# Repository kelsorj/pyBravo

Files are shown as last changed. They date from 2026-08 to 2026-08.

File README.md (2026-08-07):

## In memory of Ben Shamah

This project exists because of Ben Shamah (1973–2018).

Ben studied mechanical engineering at UC San Diego and robotics at Carnegie
Mellon, where he worked on NASA-funded robots built to explore other planets.
He brought that work back down to the bench, joining Velocity11 to build
machines that would speed up medical research — and it was there, with
colleagues including Brad Nelson, Dave Assmusen, and Chris Shaw, that the Bravo
was born. He later co-founded BioNex Solutions and led its technical side.
People who worked with him describe someone quiet and generous, who liked
puzzling out hard engineering problems and liked helping other people solve
theirs even more. He died of cancer in 2018, at 45.

The Bravo is a genuinely good machine, and a lot of them are still running. The 
goal here is to let the hardware Ben helped design join the open source 
community.

---

# pyBravo

An open-source Python driver and web control system for Bravo liquid handling
robots. It connects to the instrument over Ethernet or serial, exposes every
motion and liquid-handling operation through a REST API and a browser UI, and
runs complete pipetting workflows. It has a full simulation mode so you can
build and test protocols without touching hardware.

```bash
git clone https://github.com/kelsorj/pyBravo.git
cd pyBravo
./scripts/start_pybravo.sh      # Windows: scripts\start_pybravo.bat
```

Then open <http://localhost:8000>. Out of the box the server runs against a
simulated robot, so this works on any machine.

> [!WARNING]
> This software drives a physical robot with enough force to break labware,
> crush a pipette head, or injure a hand. Read
> [docs/safety.md](docs/safety.md) before you connect to real hardware, and
> dry-run every new protocol in simulation first.

https://github.com/user-attachments/assets/48de0bf6-f5a1-409d-ab84-00fcac42d9b6

---

## What it does

- **Direct hardware control** — connect, initialize, home, move, and jog every
  axis, with live position and state streaming over WebSocket.
- **Liquid handling** — aspirate, dispense, and mix, with configurable liquid
  classes and pipette techniques.
- **Tips and labware** — tip pickup and ejection, an editable labware catalog,
  gripper pick-and-place, and lid handling.
- **Visual workflow designer** — build protocols as a node graph in the
  browser, simulate them, then run them on the instrument.
- **Deck management** — a 3×3 deck model with per-location teachpoints, and
  obstacle-aware Z clearance when the gripper carries plates between locations.
- **3D digital twin** — watch a URDF model of the robot mirror the real
  machine's position in real time.
- **Simulation mode** — the full motion, liquid-handling, and workflow stack
  runs with no hardware attached. The optional accessories below are the
  exception: they talk to real serial ports.
- **Optional extras** — camera-based deck verification, barcode reading,
  orbital shaker control, and an LLM-assisted protocol drafter.

## Supported hardware

| Instrument generation | `controller_type` | Connection |
|---|---|---|
| Darwin-generation Bravo | `darwin_native` | TCP, port 7613 |
| Agile 7612 Bravo | `agile_7612` | TCP, port 7612 |
| Bravo SRT | `agile_srt` | TCP, port 7612 |
| Legacy Agile Bravo | `agile` | Serial, or TCP port 10000 |
| No hardware | `simulation` | — |

Details and wiring notes are in [docs/hardware-setup.md](docs/hardware-setup.md).

## Documentation

Start with the [documentation index](docs/README.md). The most-used pages:

| Page | What it covers |
|---|---|
| [Installation](docs/installation.md) | Requirements and install paths for macOS, Linux, and Windows |
| [Quickstart](docs/quickstart.md) | First run in simulation, then your first real move |
| [Hardware setup](docs/hardware-setup.md) | Networking, finding your robot, profiles, teachpoints |
| [Safety](docs/safety.md) | What can go wrong and how to avoid it |
| [User guide](docs/user-guide.md) | The web UI, end to end |
| [Workflows](docs/workflows.md) | Building and running protocols in the designer |
| [Configuration](docs/configuration.md) | Profiles, environment variables, config files |
| [API reference](docs/api-reference.md) | Every HTTP and WebSocket endpoint |
| [Architecture](docs/architecture.md) | How the codebase fits together |
| [Protocol specification](docs/protocol-spec.md) | The instrument wire protocols |
| [Troubleshooting](docs/troubleshooting.md) | Symptoms, causes, fixes |
| [FAQ](docs/faq.md) | Common questions |

## Requirements

Python 3.11 or newer. The launcher scripts use [uv](https://docs.astral.sh/uv/)
when it is available, which installs a suitable Python and all dependencies
automatically; see [Installation](docs/installation.md) for the alternatives.

## Contributing

Contributions are welcome — see [CONTRIBUTING.md](CONTRIBUTING.md) for how to
set up a development environment, run the tests, and submit a change. Please
also read the [Code of Conduct](CODE_OF_CONDUCT.md). To report a security
issue, follow [SECURITY.md](SECURITY.md).

## License

pyBravo is an independent project. It is not affiliated with, endorsed by, or
supported by Agilent Technologies, Inc. Product names are trademarks of their
respective owners and are used only to identify the hardware this software
runs. See [NOTICE](NOTICE) for the full trademark statement.

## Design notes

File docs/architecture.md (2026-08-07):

# Architecture

How pyBravo is put together, for people who intend to change it. If you only
want to run the software, start with the [Quickstart](quickstart.md) instead.

## The shape of the system

pyBravo is a layered stack. Each layer talks only to the one below it, which
is what makes it possible to support four instrument generations plus a
simulator behind one API.

```
Browser UI  (frontend/)
     │  HTTP + WebSocket
     ▼
Web layer  (pybravo/web/server.py)
     │  method calls
     ▼
Bravo facade  (pybravo/bravo.py)
     │
     ├──▶ State machine  (pybravo/state_machine/)   high-level operations as abortable tasks
     ├──▶ Deck / labware  (pybravo/deck/)           what is on the deck, and where
     ├──▶ Motion          (pybravo/motion/)         kinematics, speed profiles, path planning
     └──▶ Controller      (pybravo/controllers/, pybravo/darwin/)
                │  one class per instrument generation
                ▼
          Protocol codecs  (pybravo/protocol/)      framing, packets, CRC
                │
                ▼
          Transport        (pybravo/transport/)     TCP or serial bytes
```

The important boundary is `pybravo/controllers/base.py`. It defines the
abstract interface every backend implements — connection, motion, homing, motor
enable, device state, gripper, head detection. Everything above that line is
hardware-independent. Adding support for a new instrument means writing a new
class that satisfies that interface, and nothing above it needs to change.

## Layer by layer

### Web layer — `pybravo/web/`

`server.py` is a single large FastAPI application holding roughly 129 HTTP
routes plus one WebSocket. Routes are declared with a `_route_meta(tag, summary,
description)` helper that feeds FastAPI's OpenAPI schema, so the live
interactive docs at `/docs` stay in sync with the code. `middleware.py` logs
requests.

The single WebSocket, `/ws/state`, pushes the same payload as `GET /api/state`
on a loop. It polls at roughly 30 Hz against the simulator, and throttles to
5 Hz for real hardware so that state polling does not saturate the wire
protocol.

The web layer holds one global `Bravo` instance. It does not talk to hardware
directly.

### Facade — `pybravo/bravo.py`

The `Bravo` class is the API that applications use. It owns the profile, picks
and constructs the right controller from `profile.connection.controller_type`,
and wires together deck state, head configuration, and the state machine. If
you are writing a Python script against this project rather than using the web
UI, this is your entry point.

### State machine — `pybravo/state_machine/`

Every high-level operation — initialize, home, move to location, pick and place,
delid, aspirate, dispense, mix, tips on, tips off, scan stack height — is a
task object in `tasks.py`. `engine.py` runs them with support for abort, retry,
and ignore, which is what lets the UI recover from a recoverable error instead
of dying.

`tasks.py` is large. It is the single place where "what the operator asked for"
becomes "the ordered sequence of axis moves that accomplishes it," so it
concentrates a lot of the domain knowledge about doing things safely.

### Deck and motion — `pybravo/deck/`, `pybravo/motion/`

`deck/` models a 3×3 deck: which labware sits at each location, teachpoints for
each location, and stack tracking. `motion/` converts engineering units to
encoder ticks, applies per-axis speed profiles, and plans paths that keep the
head above obstacles.

These are pure software models. Nothing here senses the physical world, which
is why a mismatch between the model and reality causes crashes — see
[Safety](safety.md).

### Controllers — `pybravo/controllers/`, `pybravo/darwin/`

| Backend | Class | Notes |
|---|---|---|
| `simulation` | `SimulationController` | Tracks position in software; no I/O |
| `agile` | `AgileController` | Legacy instruments; serial or TCP 10000 |
| `agile_7612` | `Agile7612Controller` | Subclasses `AgileController`; TCP 7612 |
| `agile_srt` | `AgileSrtController` | Subclasses `Agile7612Controller`; four axes, no gripper |
| `darwin_native` | `DarwinController` | Separate stack under `pybravo/darwin/`; TCP 7613 |

The Agile family forms an inheritance chain, because each generation is a
variation on the one before. Darwin-generation hardware speaks a different
protocol entirely and gets its own package, with per-axis state machines for
commutation, homing, and initialization in `darwin/axis.py`.

### Protocol and transport — `pybravo/protocol/`, `pybravo/transport/`

`protocol/` holds the codecs: frame headers, packet structures, CRC, and
command encoding. The `gemini/` subpackage implements the protocol used by
Darwin-generation firmware; the `agile_7612_*` modules implement the other
family. See [Protocol specification](protocol-spec.md) for the wire formats.

`transport/` is deliberately thin — it moves bytes over TCP or a serial port
and knows nothing about their meaning. This split is what makes the protocol
layer testable with a mock transport and no hardware.

## Supporting subsystems

- **`pybravo/profile/`** — YAML-based per-machine configuration, replacing the
  Windows registry configuration older systems used. `reg_import.py` reads
  registry profile exports and legacy `.dat` directory trees so an existing
  instrument's configuration can be migrated.
- **`pybravo/workflow/`** — the node-graph protocol system: `models.py` for the
  data model, `storage.py` for JSON persistence, and `executor.py`, which walks
  the graph and dispatches state-machine tasks. The `drafter/` subpackage is the
  optional LLM assist.
- **`pybravo/vision/`** and **`pybravo/vision_service.py`** — optional
  camera-based deck verification. The camera runs in a *separate* process
  (default port 8101) because the SDK is a heavy, optional dependency; the main
  server talks to it over HTTP via `vision_client.py`, and works fine when it is
  absent.
- **`pybravo/accessories/`** — barcode reader and orbital shaker drivers, with a
  manager handling their lifecycle.
- **`pybravo/model/`** — the URDF robot model and meshes that the browser renders
  as a live digital twin.

## How a request becomes motion

Tracing `POST /api/move` end to end:

1. FastAPI parses the request and calls the handler in `server.py`.
2. The handler calls the corresponding method on the global `Bravo` instance.
3. `Bravo` creates the appropriate task and hands it to the state machine
   engine, which can abort or retry it.
4. The task consults motion and deck state to turn the requested engineering
   units into a safe target in encoder ticks.
5. The task calls the controller's `move` method — the first hardware-specific
   step.
6. The controller encodes the command through the protocol codec.
7. The transport writes bytes to the socket or serial port.
8. Position updates flow back up and are broadcast to every browser over
   `/ws/state`.

## Testing strategy

The transport boundary is what makes this testable. Most protocol and
controller tests substitute a mock transport that replies with well-formed
frames, so the full encode/decode path runs with no instrument attached.

- `tests/protocol/gemini/` — codec-level tests for framing, packets, instructions
- `tests/darwin/` — axis state machines, homing, safety limits, motion, topology
- `tests/test_agile_srt_homing.py` — a golden-file test pinning the SRT homing
  frame sequence, because homing is the operation most likely to damage hardware
  and cannot be exercised in CI
- `tests/test_web_server.py` — API endpoint behavior
- `tests/test_bravo_init.py` — the facade's behavior, the largest suite

Run everything with `uv run --extra dev python -m pytest`.

## Extending it

**A new instrument generation:** subclass `BravoController` (or the closest
existing Agile class), implement the interface, add your `controller_type` to
the selection logic in `pybravo/bravo.py`, and add a profile. If the wire format
differs, add a codec under `pybravo/protocol/` rather than putting encoding
logic in the controller.

**A new high-level operation:** add a task in `pybravo/state_machine/tasks.py`,
expose it on `Bravo`, then add a route. Keeping the logic in the task means it
works from the API, from the workflow executor, and from a Python script.

**A new workflow node:** add the node type to the designer, then map it to a
task in `NODE_TYPE_MAP` in `pybravo/workflow/executor.py`.

**A new accessory:** add a driver under `pybravo/accessories/` and register it
with the manager.

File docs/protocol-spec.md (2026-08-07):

# Protocol specification

The wire protocols pyBravo speaks to Bravo instruments. This page is for
people maintaining the driver or adding support for another instrument
generation; you do not need it to operate the software.

Two protocol families are implemented. Which one applies depends on your
instrument's controller generation.

| Family | Instruments | `controller_type` | Port |
|---|---|---|---|
| Gemini | Darwin-generation | `darwin_native` | TCP 7613 |
| V11 / Agile | Agile, Agile 7612, SRT | `agile`, `agile_7612`, `agile_srt` | TCP 7612, TCP 10000, or serial |

Neither protocol has authentication or encryption. Anyone with network access to
the instrument can command it — see [SECURITY.md](../SECURITY.md).

## Gemini protocol (Darwin-generation)

Implemented in `pybravo/protocol/gemini/`.

### Outer TCP frame

Every message is an 8-byte header followed by a payload:

| Offset | Size | Field | Value |
|---|---|---|---|
| 0–1 | 2 | `msg_sync` | `0xAAAA`, little-endian |
| 2–3 | 2 | `protocol_version` | `0x0001`, little-endian |
| 4–5 | 2 | `payload_type` | little-endian uint16 |
| 6–7 | 2 | `payload_size` | little-endian uint16, bytes following |
| 8… | n | `payload` | interpreted per `payload_type` |

### Payload types

| Value | Name | Payload |
|---|---|---|
| 1 | `PACKET` | Exactly 8 bytes — one packet |
| 4 | `MULTIPACKET` | Up to 512 bytes. Outgoing: N concatenated 8-byte packets. Incoming: an 8-byte response |
| 5 | `SERIAL_DATA` | Exactly 9 bytes — a serial-peripheral payload |

Packet encoding, instruction encoding, and the enum tables live in
`packet.py`, `instruction.py`, and `enums.py`. An instruction is the 4-word
encoding used for motion, delay, and tip operations.

### Axis control

Darwin-generation axes are not initialized through a single firmware call.
Commutation, homing, and initialization are each driven step by step through
`SUBCMD_MOTOR_STATE` writes and polled state reads, implemented as per-axis
state machines in `pybravo/darwin/axis.py`. Driving them explicitly is what
makes retry-on-regression and the timing-sensitive behavior possible.

## V11 / Agile protocol

Implemented in `pybravo/protocol/agile_packet.py`,
`agile_7612_packet.py`, `agile_7612_commands.py`, `agile_7612_crc.py`,
`v11_comm.py`, and `v11_agile_7612_comm.py`.

### Frame order differs by generation

This is the single most important difference, and getting it backwards produces
frames the instrument silently ignores:

- **Legacy Agile:** `[length][cmd][data]`
- **Agile 7612 and SRT:** `[cmd][length_u16_LE][data]`

### Checksum

Agile 7612 and SRT use **CRC-8/MAXIM** (Dallas 1-Wire): polynomial `0x8C`, the
reflected representation of x⁸+x⁵+x⁴+1, with `init=0x00`. This is *not*
CRC-8/SMBUS (`0x07`), and the two agree often enough on short inputs to make a
mistake here hard to spot.

### Agile packets

Command `0xA1` frames carry a 10-byte Agile packet followed by a one-byte axis
index. Byte semantics that matter:

- **Byte[1]** is the axis bitmask for status and trigger commands.
- **Byte[7]** carries the register or operation selector. Notably, the status
  register `0x90` goes in **byte[7]**, not byte[1] — a common error.

Selected byte[7] values:

| Value | Meaning |
|---|---|
| `0x10` | Servo register write |
| `0x31` | Fault reset |
| `0x38` | Move trigger |
| `0x52` | Homing-complete marker |
| `0x90` | Status read |

### Motion commands

| Command | Purpose |
|---|---|
| `0xA2` | `PREPARE_MOVE` — 17-byte struct on Agile 7612 and SRT |
| `0xAA` | `PREPARE_JOG` — force-controlled moves only |
| `0xA7` | Position read |

`PREPARE_JOG` (`0xAA`) is used **only** for force-controlled tip pickup.
Ordinary jogs from the UI use `PREPARE_MOVE` (`0xA2`) followed by a trigger
(byte[7] = `0x38`). Using `0xAA` for a normal jog applies force where none is
wanted.

### Header selection

Servo register writes use a header of `local_axis * 0x10`. Two operations do
not follow that rule:

- **Home-complete register writes** use header `0x01`.
- **The homing-complete marker** (byte[7] = `0x52`) uses header `0x00`.

### Homing

Homing is host-driven and stateful. The ordering constraints are real
requirements, not conventions:

1. Register `0x4A` must be **read** before homing begins.
2. After servo configuration, register `0x10` must be **read** via header
   `0x09`. Without both reads the firmware never enters homing mode, and the
   failure is silent.
3. The phase pattern is chosen at runtime from the home-sensor state in register
   `0x10`: on-sensor gives a 2-phase home (depart, then slow approach back);
   off-sensor gives a 3-phase home (approach, depart overshoot, slow approach).
4. A homing-complete marker (byte[7] = `0x52`) is sent per axis, with an empty
   data field. The X and Y markers can carry situational data bytes; those must
   not be replayed from one homing scenario into another.

`tests/test_agile_srt_homing.py` pins the complete SRT homing frame sequence,
because homing is the operation most likely to damage hardware and cannot be
exercised in CI.

### Generation-specific notes

**Agile 7612.** Two servo controllers, indexed 0 and 4. Controller 2 requires a
fault reset (mask `0x01`, axis index 4, byte[7] = `0x31`) after **every** move,
not only during G-axis homing. The firmware supports neither ADC head read
(`0xB3`, which causes audible clicking) nor smart head detect (`0xB5`), so head
type must be configured manually.

**SRT.** Four axes — X, Y, Z, W — with no gripper, and four servo controllers
indexed 0–3, so homing servo headers are `0x00`, `0x10`, `0x20`, `0x30`. Homing
order is Z, W, X, Y. The home-complete register field in `PREPARE_MOVE` is
encoded `0x01nn`. The W (pipettor) axis needs a pump-parameter pre-config block
written before its homing servo configuration, and a distinct register-`0xA0`
value.

## Units and scaling

Positions cross the wire as encoder ticks. Conversion to engineering units uses
each axis's `ticks_per_eng_unit` from the profile.

The W axis is the trap: its `ticks_per_unit` must come from the profile
(448.0), not the inherited default (48.0). A wrong value here means every
volume is wrong by roughly a factor of nine.

## Known measurement limitations

- The W position register is unstable, with a spread of roughly 5–10 µL between
  consecutive reads. Static readings are directionally correct but noisy.
- Controller 2 position reads (G and Zg) are unreliable while motion is active.
  At-rest values are correct.

## Adding a new generation

Add a codec under `pybravo/protocol/` and a controller under
`pybravo/controllers/` implementing the interface in `base.py`. Keep encoding in
the codec, not the controller. The transport layer is deliberately thin, so a
mock transport lets you test the full encode/decode path with no instrument —
see [Architecture](architecture.md).

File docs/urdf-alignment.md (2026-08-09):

# URDF head alignment (3D view only)

> **Status: all three axes are fixed.**
>
> - **Z — done.** The head was drawn one teach-tip too low. Corrected via the
>   live `head.teach_tip_length_mm`; see "The Z axis" below.
> - **X and Y — done.** Fixed as measured gantry datums in `JOINT_AXIS_MAP`
>   (`xaxis: 182.64`, `yaxis: 2.3`), not by moving the drawn tips; see "The X/Y
>   datum" below. Two earlier attempts moved the tips instead of the gantry and
>   were reverted — "Two alignments, not one" below explains why that can never
>   work, and remains the most useful thing on this page.
>
> All of this is cosmetic. Real motion is unaffected.
>
> **Confirmation recording:**
> [docs/media/tips-on-off-simulation.mov](media/tips-on-off-simulation.mov) — a
> simulate run captured after the fixes: the head descends aligned with the
> box, the tips leave the box and attach at the bottom of the press, ride up
> with the head, and are released into the destination box at the eject.
> (GitHub plays committed videos from the file's blob page; open the link.)

> **Scope: the 3D view, and nothing else.**
>
> Real motion is correct. Tips on and tips off work on hardware in full, row,
> column and partial modes, on both 96 and 384 heads. The commanded positions,
> the teachpoints, and the geometry in `pybravo/deck/geometry.py` and
> `pybravo/head_mode.py` are therefore **authoritative and out of scope**.
> Nothing described here may change a commanded position, and no change made
> for the reasons in this document belongs anywhere except
> `frontend/src/robot-scene.js`.
>
> If a proposed change to the 3D view would require editing anything under
> `pybravo/`, the proposal is wrong.

## The problem this existed to solve

In the 3D view the head's barrels were drawn a couple of columns away from the
wells they were actually over — worst at the edge of an empty tip box, where
the tips visibly hung off the end.

## The X/Y datum — diagnosed and fixed

The error was in the gantry's visual datum, not in where the tips sit on the
head. Measured with the head-tip array (placed from the head mesh) against the
rendered wells, at four commanded poses spanning 99 mm of X travel and both
deck rows:

| | error, every pose |
|---|---|
| X | **−10.40 mm** (≈2.3 columns), constant |
| row (robot Y) | **+2.40 / +2.19 mm** per location (mean ≈ half a pitch) |

Constant across the whole span in both axes — a datum error, not scale. Both
derivatives measured exactly 1 mm world per commanded mm, so the correction is
a pure `homeOffset` shift in `JOINT_AXIS_MAP` (`frontend/src/robot-scene.js`):
`xaxis` 193.04 → **182.64**, `yaxis` 0 → **2.3**. After the change the residual
is 0.00 mm in X and ±0.11 mm in row at all four poses — the ±0.11 is the two
locations' real taught difference, which a flat model deck cannot represent.

Why this works where the two reverted attempts could not: `homeOffset` moves
the **whole gantry chain** — head mesh, attached tips, and gripper together, as
on the real machine (they share one carriage; confirmed against the URDF joint
tree, where both hang under `ygantry` ← `xgantry`). The tips↔mesh relationship
is preserved by construction (barrel-to-tip gap 17.9 mm before and after), and
deck pads and labware are static children of the base and do not move. The
earlier attempts moved only the drawn tips, which can satisfy tips↔labware or
tips↔mesh but never both.

The remaining per-location ±0.1 mm class of residual would only be removable by
modelling the deck's taught Z/XY variation, which is not worth it for a
visualization.

This document is the definition the renderer should use instead.

## The invariant

> When the robot is commanded to a position, the **rendered** head's A1 barrel
> must appear at the deck position that command implies — for every head type,
> every labware format, and every head mode.

Equivalently, and more usefully as a test: when a tip operation is commanded
against the A1 anchor of a piece of labware, the rendered A1 barrel sits on the
rendered A1 well.

## Two alignments, not one

This is the trap that has already cost a round of work. There are two
relationships, and a change to the drawn tip positions trades one against the
other:

| | what it means | how it is currently satisfied |
|---|---|---|
| tips ↔ head mesh | the drawn tips sit under the head's visible barrels | correct today, because the tips are placed from the mesh bounding box |
| tips ↔ labware | the drawn tips sit over the wells they are commanded to | wrong today, by the constant above |

Moving the drawn tips can only ever satisfy one of these. Fixing this properly
means establishing where A1 is **in the model**, so both hold at once.

**Any verification must check both.** A measurement that only checks tips against
labware will report success while the tips float away from the head.

## What the backend already fixes for us

Read-only facts, established from the code. These are inputs to the render, not
things to change.

**Barrel grids** — `head_geometry_for_type`, `pybravo/head_mode.py`:

| head type | grid (rows × cols) | pitch |
|---|---|---|
| `HT_384_D_70`, `_S2`, `HT_384_F_50`, `HT_384_PINTOOL` | 16 × 24 | 4.5 mm |
| 96-format (the fallback) | 8 × 12 | 9.0 mm |
| `HT_1536_PINTOOL` | 32 × 48 | 2.25 mm |
| `HT_16_D_ST` | 16 × 1 | 4.5 mm |
| `HT_8_D_LT` | 8 × 1 | 9.0 mm |

**Corner and axis conventions** — pinned by the Head Mode picker, which draws
BACK as −Y, LEFT as −X, and marks the anchor corner at back-left:

- A1 is the **back-left** barrel: minimum X, minimum Y.
- Column index increases toward **+X** (right).
- Row index increases toward **+Y** (front).

**Head A1 offsets between formats** — from the hardware, not from code: the
384 head's A1 barrel sits **2.25 mm left and 2.25 mm back** of the 96 head's A1
barrel. The two grids are concentric at different pitches, so their A1 corners
do not coincide.

## How this was defined in the end

The original plan on this page was a per-head-link constant (`A1_OFFSET`,
placing the barrel array within the head link). The fix that actually shipped
is simpler and sits one level up: the error was the same for the whole gantry,
so it lives in the per-joint `homeOffset` datums in `JOINT_AXIS_MAP`, and the
tips stay placed from the head mesh exactly as before. A per-head constant
would only become necessary if a head's *mesh* were misplaced within its own
link — no evidence of that once the gantry datum was corrected.

If a future head model does need a per-link constant, the measurement
procedure is unchanged: command the A1 anchor over a known box, read where the
mesh's barrels render versus the wells, at two distant locations (the value
must be constant), and for the 96/384 pair check their difference comes out at
(2.25, 2.25) — the two grids are concentric at different pitches.

## Verification

A fix is only complete when all of these hold:

1. **tips ↔ labware**: the rendered A1 barrel sits on the rendered A1 well when
   commanded to the A1 anchor, for both head formats.
2. **tips ↔ head mesh**: the rendered tips sit under the head mesh's own
   barrels — checked visually and by comparing tip positions against mesh
   barrel positions.
3. **Pose independence**: both hold at several positions across the deck, not
   just the one used to derive the constant.
4. **Mode independence**: both hold for full, row, column and partial modes.
5. **`git diff --name-only -- pybravo/` is empty.** No Python changed, so no
   commanded position can have changed.

## The Z axis — diagnosed and fixed

The head rendered one **teach tip** too low, at every Z.

Robot Z is referenced to the tip of the teach tip, not to the barrel face: the
backend computes `deck_surface_z = teach_z + teach_tip_length`. The renderer
placed the head as though Z meant the barrel, so it sat low by exactly that
length.

Measured against the deck surface, head mesh only, with the synthetic tips
excluded — they are children of the head link and contaminate the measurement
if included, which is how an earlier pass produced a spurious 44.1 mm:

| | before | after |
|---|---|---|
| loc 1 (50 mm box), Z = 0, 50, 100, 115.1, 140, 165.1 | −26.14 mm at every Z | **−0.04 mm** |
| loc 4 (25 mm box), Z = 0, 50, 100, 115.1, 140, 164.9 | −25.94 mm at every Z | **+0.16 mm** |

Constant across Z, independent of labware height, and −26.04 mm on average
against a nominal `teach_tip_length_mm` of 26.1. The residual ±0.1 mm is the
0.20 mm difference between the two locations' taught Z, which a flat model deck
cannot represent — it is real machine variation, not modelling error.

The fix uses the `homeOffset` mechanism already present in `JOINT_AXIS_MAP`,
which at the time was calibrated for X (193.04 — since re-measured to 182.64,
see "The X/Y datum" above) and Zg (−20) but left at 0 for Z. The value
is taken live from `head.teach_tip_length_mm` on `/api/profile` rather than
hardcoded, so a different head or teach tip follows automatically, with the
common 26.1 seeded as a fallback.

Two things were checked because they could have been broken silently:

- **Tips still sit on the head.** The gap between the barrels and the tips'
  bottoms is 17.9 mm before and after. The whole head link moves, so this
  relationship is preserved by construction — unlike the X/Y attempts, which
  moved only the drawn tips.
- **The gripper did not move.** `zaxis-gripper` is coupled to Z, so it could
  have been dragged along; measured at 87.8 mm before and after, unchanged.

### `tip_offsets.yaml` was never the problem

Worth stating plainly, because it is the intuitive place to look. The backend
already resolves `config/tip_offsets.yaml` and folds the result into the
commanded Z: `deck_surface_z - labware_height`, then the eject offset. Moving
between the Tips On and Tips Off poses raised the head by exactly 14.2 mm in the
view, which is `tips_off_z_offset: 14.0` arriving intact.

**Those offsets are therefore already in the Z the renderer receives, and must
not be applied again there — that would double-count them.** What the view was
missing was the datum, not the offsets.

### A more durable version of this fix

The backend computes `deck_surface_z` in the tips motion path (`executor.py`)
but does not send it to the frontend. Sending it would let the renderer derive
the Z datum from the deck directly, rather than reconstructing it from the teach
tip length. Worth doing if this ever drifts again.

## Open questions

- The X/Y/Z datums were measured with the 384 head model. If a 96-head mesh is
  ever added to the URDF, re-run the four-pose sweep with it — the gantry
  datums should hold (they are properties of the gantry, not the head), and any
  residual would indicate the new head mesh is misplaced within its link.
- The datums are tied to this revision of the URDF. If the URDF is re-exported,
  re-measure — the sweep takes minutes and the procedure is above.

## Notes for whoever picks this up

The renderer currently falls back to `_getHeadTipMountFrame` whenever it lacks
better information, which is the right shape — keep a fallback so the tips are
always drawn somewhere sane, and prefer the defined constant when available.

Be aware that the designer pauses the `/ws/state` socket while a simulation runs
(`setSimulationMode`), so anything the renderer needs from server state must not
depend on that socket being live. A previous attempt at this fix was correct but
never executed for exactly that reason.

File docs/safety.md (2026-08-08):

# Safety

pyBravo drives a physical robot with motors strong enough to break labware,
destroy a pipette head, and injure a hand. This page is the one document you
should read before connecting to real hardware.

> [!WARNING]
> This software is provided under the GNU General Public License v3.0 or later,
> **without warranty of any kind and without any fitness-for-purpose
> guarantee**. It is not a
> validated instrument control system, it is not certified for clinical,
> diagnostic, or GxP use, and it has not been safety-certified by any body. You
> are responsible for the safe operation of your instrument.

## The short version

1. Simulate first. Every new or edited protocol runs in `simulation` before it
   runs on metal.
2. Keep a hand near the emergency stop the first time any new motion executes.
3. Verify teachpoints after any mechanical change, head swap, or deck change.
4. Never run a workflow you have not read, including one generated for you.
5. Watch the first full run of any protocol end to end. Do not walk away.

## What can actually go wrong

**Head-into-deck crash.** The Z and W axes carry the pipette head down toward
the deck. A wrong teachpoint, a wrong `ticks_per_eng_unit`, a labware
definition with the wrong height, or a plate that is present when the software
thinks the location is empty will drive the head into a hard surface. This is
the most common way to cause expensive damage, and it happens fast enough that
you cannot react in time. It is prevented by correct configuration, not by
reflexes.

**Crash during homing.** Homing moves axes toward their limits, sometimes at
speed, and it runs before the software knows where anything is. If the deck is
not clear, homing is when you find out. Clear the deck before homing.

The order matters and is enforced in code (`SAFE_HOME_ORDER` in
`pybravo/types.py`): **Z, then Zg, then G, then X and Y, then W.** The head and
gripper must lift before the gantry moves laterally, or an unhomed head sitting
low is dragged sideways through whatever is on the deck. `HomeTask` also tries
to retract Z and dock the gripper first, but both of those steps are skipped
when the axes are not yet homed — which is exactly the cold-start case — so the
ordering is the real guarantee. Do not reorder it without understanding what is
physically above the deck at each step.

Sequence axes on the server, never in a client. `POST /api/home_axis` accepts
`{"axes": ["X", "Y", "Z"]}` and orders the group; issuing one request per axis
bypasses the invariant entirely, because a single-axis request has no order to
correct.

**Gripper and pick-and-place collisions.** Moving labware between locations
assumes the destination is empty and the path is clear. If the deck state in
software disagrees with the deck in front of you, the robot will move as though
its model is correct.

**Tip pickup force.** Tip pickup presses the head down onto a tip box with
deliberate force. A misaligned tip box, the wrong tip definition, or a wrong
head mode turns that force into damage.

**Pinch and crush points.** The moving head and gripper have no light curtain
in most configurations. Do not reach into the work envelope while the
instrument is powered and enabled, even when it appears idle — a queued command
or a network message can start motion with no warning.

**Liquid hazards.** The software does not know what is in your plates. Aspirate
and dispense operations with the wrong volumes or the wrong liquid class can
spray, aerosolize, or cross-contaminate. Apply your own lab's handling rules for
whatever is on the deck.

## Before you connect to hardware

- Read [Hardware setup](hardware-setup.md) and build a profile for your
  specific instrument. Do not reuse another lab's profile: teachpoints, axis
  ranges, and calibration are machine-specific.
- Confirm `controller_type` matches your instrument generation. Speaking the
  wrong protocol to a robot produces undefined behavior.
- Confirm axis ranges and `ticks_per_eng_unit` are right. If ticks-per-unit is
  wrong, a commanded 10 mm move can travel 100 mm.
- Know where the emergency stop is, and confirm it works, before the first move.
- Clear the deck.

## Before each run

- Confirm the deck in software matches the deck in reality: right labware, right
  locations, lids where the protocol expects them.
- Confirm the head type in the profile matches the head physically installed.
  On Agile 7612 instruments the firmware cannot report the head type, so nothing
  will catch this mistake for you.
- Simulate the run and read the motion sequence.
- For a protocol's first run on hardware, consider running it with empty
  labware.

## Working on the code

If you are changing anything in `pybravo/controllers/`, `pybravo/motion/`,
`pybravo/state_machine/`, or `pybravo/darwin/`, you are working on the parts
that can break a machine.

- Never widen an axis range, raise a current limit, or remove a sensor check
  without saying so explicitly in your pull request.
- Homing and tip-pickup sequences carry the most risk. `tests/test_agile_srt_homing.py`
  pins the SRT homing frame sequence precisely so that an accidental change is
  caught; if it fails, treat that as a real signal.
- Prefer failing closed. When state is unknown, stop rather than assume.
- Test in simulation, then on hardware with a clear deck, then in normal use.

## Known limitations that affect safety

- **Head detection is unavailable on Agile 7612 instruments.** The firmware
  supports neither ADC read nor smart head detect, so the head type must be set
  manually in the profile and cannot be verified by software.
- **The W position register is noisy**, with a spread of roughly 0.05-0.1 µL between
  reads. Do not build logic that depends on precise in-motion W readings.
- **Controller 2 position reads (G and Zg) are unreliable during motion.**
  At-rest values are correct; in-motion values jump.
- **The deck model is software state.** Nothing physically senses whether a
  plate is where the software believes it is, unless you have the optional
  camera-based deck verification configured.

## Emergency stop

Know your instrument's physical emergency stop before you begin. In software,
`POST /api/abort` stops the running task and `POST /api/workflows/stop` aborts a
running workflow, but **software abort is not a substitute for the physical
emergency stop.** A hung process, a dropped network connection, or a crashed
browser tab cannot stop a moving axis. The hardware stop can.

## Reporting a safety problem

If you find a defect that could cause injury or damage, please report it
privately first — see [SECURITY.md](../SECURITY.md). Do not open a public issue
containing a working reproduction that would crash someone else's instrument.

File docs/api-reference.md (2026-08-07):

# pyBravo HTTP & WebSocket API Reference

pyBravo exposes a FastAPI backend (`pybravo/web/server.py`) that drives Bravo liquid-handling
robots, manages deck and labware configuration, stores profiles, and runs the workflow designer.

- **Base URL:** `http://localhost:8000` (the server binds `0.0.0.0:8000` by default; see `run_server()`)
- **Interactive docs:** `http://localhost:8000/docs` (Swagger UI), `http://localhost:8000/redoc`,
  raw schema at `http://localhost:8000/openapi.json`
- **CORS:** all origins, methods, and headers are allowed.

## Content types

| Direction | Type | Used by |
|---|---|---|
| Request | `application/json` | Most `POST`/`PUT`/`PATCH` endpoints (Pydantic models) |
| Request | `multipart/form-data` | File uploads (labware assets, PDF and JSON imports) |
| Request | query string | A handful of endpoints take scalars as query parameters — noted per route |
| Response | `application/json` | Default for every `/api/*` route |
| Response | `text/html` | Page routes (`/designer`, `/labware-editor`, …) |
| Response | `image/png`, `image/jpeg` | Camera previews and rendered PDF pages |

## Errors

Four error shapes are produced, all JSON:

| Condition | Status | Body |
|---|---|---|
| `RuntimeError` (e.g. not connected, no address configured) | `400` | `{"error": "<message>"}` |
| `BravoError` (hardware/protocol failure) | `400` | `{"error": "<message>", "error_type": "<ErrorType name>"}` |
| `HTTPException` raised by a handler | as raised | `{"detail": <string or object>}` |
| Request body fails validation | `422` | `{"detail": [<pydantic errors>]}` |
| Any unhandled exception | `500` | `{"error": "Internal server error"}` |

Common `HTTPException` statuses in this codebase: `400` (bad argument), `404` (unknown id /
feature disabled), `409` (conflicting state — already connected, name already taken),
`500`/`501`/`502`/`503` (upstream service unavailable or not installed).

A few handlers return `{"status": "error", "message": …}` with HTTP `200` instead of raising —
notably `POST /api/execute_command` for an unrecognised command name.

---

## ⚠️ Endpoints that move physical hardware

This software drives a robot with a moving gantry, pipette head, and gripper. **Every endpoint in
the table below can cause physical motion.** Before calling any of them, confirm the deck is clear,
the enclosure is safe, and nobody's hands are inside the working envelope.

| Endpoint | What moves |
|---|---|
| `POST /api/initialize` | Full initialization sequence including homing |
| `POST /api/home` | All axes home, then travel to park positions |
| `POST /api/home_axis` | One axis homes |
| `POST /api/move` | One axis to an absolute position |
| `POST /api/jog` | One axis by a relative step |
| `POST /api/tip_force_jog` | Z axis under force control |
| `POST /api/move_to_location` | X/Y/Z travel to a taught deck location |
| `POST /api/move_safe_z` | Z retracts to the safe height |
| `POST /api/aspirate` | Travel + plunger motion |
| `POST /api/dispense` | Travel + plunger motion |
| `POST /api/tips_on` | Head presses into a tip box |
| `POST /api/tips_off` | Head ejects/returns tips |
| `POST /api/gripper/open` | Gripper jaws |
| `POST /api/gripper/close` | Gripper jaws |
| `POST /api/gripper/dock` | Gripper jaws + gripper Z |
| `POST /api/pick_place` | Full labware transfer between two locations |
| `POST /api/execute_command` | Dispatches to any of the above task APIs |
| `POST /api/workflows/{workflow_id}/execute` | Runs an entire workflow graph against live hardware |
| `POST /api/motor/enable`, `/disable`, `/enable_all`, `/disable_all` | No commanded motion, but disabling a servo can let a loaded axis drop under gravity |

**Destructive or disruptive endpoints** (no motion, but data loss or service interruption):
`POST /api/shutdown`, `DELETE /api/workflows/{id}`, `DELETE /labware/types/{id}`,
`DELETE /labware/classes/{id}`, `DELETE /liquid-classes/{id}`,
`DELETE /pipette-techniques/{id}`, `DELETE /tips/{id}`, `DELETE /api/deck/{location}/labware`,
`POST /api/profile/rename`, and `POST /api/profile/import_reg` /
`POST /api/profile/import_dat` when called with `overwrite: true`.

---

## Table of contents

- [Connection & Lifecycle](#connection--lifecycle)
- [Motion](#motion)
- [Teachpoints](#teachpoints)
- [Head & Tips](#head--tips)
- [State & Diagnostics](#state--diagnostics)
- [Vision](#vision)
- [Labware](#labware)
- [Liquid Classes & Pipette Techniques](#liquid-classes--pipette-techniques)
- [Deck](#deck)
- [Profiles](#profiles)
- [Device Discovery](#device-discovery)
- [Workflows](#workflows)
- [Workflow Drafting (LLM)](#workflow-drafting-llm)
- [HTML pages and static mounts](#html-pages-and-static-mounts)
- [WebSocket: `/ws/state`](#websocket-wsstate)

---

## Conventions

**Axis names** (`X`, `Y`, `Z`, `W`, `G`, `Zg`) are matched case-insensitively. `W` is the plunger,
`G` the gripper jaws, `Zg` the gripper vertical axis. An unknown name returns `400`.

**Speed levels** are `FAST`, `MED`, `SLOW`, `HOMING`, `SAFE` (case-insensitive). Omitting `speed`
uses `MED`. An unknown value returns `400`.

**Deck locations** are integers `1`–`9`.

**Head types** are `HeadType` enum names, e.g. `HT_96_D_200`, `HT_96_D_70`, `HT_384_D_70`,
`HT_96_F_50`, `HT_96_ASSAYMAP`, `HT_96_PINTOOL`, `HT_384_PINTOOL`, `HT_1536_PINTOOL`,
`HT_UNKNOWN`.

**Controller types** referenced across the API: `simulation`, `agile`, `agile_7612`, `agile_srt`,
`darwin_native`, `darwin_serial`.

**"Requires a connection"** below means the endpoint calls into the controller and will fail with
`400 {"error": "Not connected"}` (or an equivalent `RuntimeError`) if no transport is open.

---

## Connection & Lifecycle

### POST `/api/connect`

Opens the configured controller transport and persists the resulting connection settings back into
the active profile. Any omitted field falls back to the value already stored in the profile. This
endpoint does **not** run initialization — call `POST /api/initialize` for that.

Request body — `ConnectRequest`:

| Field | Type | Notes |
|---|---|---|
| `controller_type` | `string \| null` | Falls back to the profile value |
| `address` | `string \| null` | IP address; required for `agile`, `agile_7612`, `agile_srt`, `darwin_native` |
| `serial_port` | `string \| null` | Required for `darwin_serial` |

Response: `{"status": "connected", "controller": "<controller_type>"}`

Errors: `400` when no address/serial port is configured for the selected controller type, or when
the socket cannot be opened.

### POST `/api/disconnect`

Closes the active controller connection.

Response: `{"status": "disconnected"}`

### POST `/api/shutdown`

**Destructive.** Best-effort disconnect, then hard-exits the server process shortly after the
response is flushed. Intended for a UI "Quit" button; it bypasses the graceful shutdown path.

Response: `{"status": "shutting_down"}`

### POST `/api/initialize`

⚠️ **Moves hardware.** Runs the device initialization sequence using the active profile, connecting
first if no session is open. Initialization homes axes and drives the robot to a known state.

Request body: none.

Response: `{"status": "initialized", "controller": "<controller_type>"}`

Errors: `400` when no address/serial port is configured, or the connection fails.

### POST `/api/home`

⚠️ **Moves hardware.** Retracts to safe Z, docks the gripper when one is present, homes the machine
axes, and moves the homed axes to their park positions. Requires a connection.

Response: `{"status": "homed", "axes": ["X", "Y", ...]}`

### POST `/api/abort`

Signals the task engine to abort the currently running operation.

Response: `{"status": "aborted", "accepted": <bool>}`

### POST `/api/retry`

Retries the current failed state-machine step.

Response: `{"status": "retried", "accepted": <bool>}`

### POST `/api/ignore`

Ignores the current task error and continues to the next step.

Response: `{"status": "ignored", "accepted": <bool>}`

---

## Motion

Every endpoint in this section requires an active hardware connection and moves the robot.

### POST `/api/move`

⚠️ **Moves hardware.** Absolute single-axis move in engineering units.

Request body — `MoveRequest`:

| Field | Type | Default |
|---|---|---|
| `axis` | `string` | required |
| `position` | `float` | required |
| `velocity` | `float` | `0.0` (controller default) |
| `acceleration` | `float` | `0.0` (controller default) |

Response: `{"status": "moved", "axis": "<axis>", "position": <float>}`

### POST `/api/jog`

⚠️ **Moves hardware.** Relative single-axis jog, used for manual positioning and teaching.

Request body — `JogRequest`:

| Field | Type | Default | Notes |
|---|---|---|---|
| `axis` | `string` | required | |
| `step` | `float` | required | Magnitude; sign is taken from `direction` |
| `direction` | `int` | `1` | `>= 0` positive, negative otherwise |
| `speed` | `string \| null` | `MED` | Speed level name |
| `peak_current` | `float \| null` | `null` | When set, performs a force-limited jog |

Response: `{"status": "jogged", "axis": "<axis>", "step": <signed float>, "position": <float>}`

### POST `/api/tip_force_jog`

⚠️ **Moves hardware.** Experimental force-controlled jog with position-based settle detection, used
for diagnosing tip-pickup behaviour. Reads the current position, computes `current + step` as the
travel limit, and drives the axis under a current cap.

Request body — `JogRequest` (same shape as `/api/jog`; `peak_current` defaults to `0.10` here).

Response:

```json
{"status": "jogged", "axis": "Z", "step": -2.0, "position": 12.3,
 "start": 14.3, "max_position": 12.3, "peak_current": 0.1}
```

Errors: `400` when the active controller does not implement `tip_force_jog`.

### POST `/api/home_axis`

⚠️ **Moves hardware.** Homes a single axis.

Request body — `AxisRequest`: `{"axis": "<axis>"}`

Response: `{"status": "homed", "axis": "<axis>"}`

### POST `/api/motor/enable`

Enables servo power for one axis. Request body — `AxisRequest`. Response:
`{"status": "enabled", "axis": "<axis>"}`

⚠️ Enabling or disabling a servo changes whether a loaded axis is held in place.

### POST `/api/motor/disable`

Disables servo power for one axis so it can be repositioned by hand. Request body — `AxisRequest`.
Response: `{"status": "disabled", "axis": "<axis>"}`

⚠️ A disabled vertical axis can drop under gravity.

### POST `/api/motor/enable_all`

Enables servo power on every axis. No request body. Response: `{"status": "all_enabled"}`

### POST `/api/motor/disable_all`

Disables servo power on every axis. No request body. Response: `{"status": "all_disabled"}`

⚠️ Disables the vertical axes as well — support the head before calling.

### POST `/api/move_to_location`

⚠️ **Moves hardware.** Sends the head to a taught deck location: retract Z to safe height, move X/Y
to the taught coordinates, then lower Z to the taught position or to an approach height above it.
The location must already have a valid teachpoint.

Request body — `MoveToLocationRequest`:

| Field | Type | Default |
|---|---|---|
| `location` | `int` | required |
| `approach_height` | `float` | `0.0` |
| `only_move_z` | `bool` | `false` |
| `speed` | `string \| null` | `MED` |

Response: `{"status": "moved", "location": <int>, "approach_height": <float>, "only_move_z": <bool>, "speed": "<SPEED>"}`

### POST `/api/move_safe_z`

⚠️ **Moves hardware.** Retracts the liquid-handling Z axis to the profile's configured safe
position. Z only.

Request body — `SpeedRequest`: `{"speed": "<string|null>"}`

Response: `{"status": "moved_safe_z", "speed": "<SPEED>"}`

### POST `/api/aspirate`

⚠️ **Moves hardware.** Runs an aspirate task at a taught location: retract, travel, lower to the
working depth, aspirate, retract. Tips and head configuration must already be correct.

**Query parameters** (not a JSON body):

| Parameter | Type |
|---|---|
| `location` | `int` |
| `volume` | `float` (µL) |

Response: `{"status": "completed"}`

For the full parameter set (pre/post-aspirate, distance from bottom, liquid class, technique) use
`POST /api/execute_command` with `command: "aspirate"`.

### POST `/api/dispense`

⚠️ **Moves hardware.** Runs a dispense task at a taught location.

**Query parameters:** `location` (`int`), `volume` (`float`, µL).

Response: `{"status": "completed"}`

### POST `/api/tips_on`

⚠️ **Moves hardware.** Picks up disposable tips from a tip-box location, using the active head mode
and tip-selection anchor to decide which tips are acquired.

**Query parameter:** `location` (`int`).

Response: `{"status": "completed"}`

### POST `/api/tips_off`

⚠️ **Moves hardware.** Returns or discards the tips currently on the head at the given location.

**Query parameter:** `location` (`int`).

Response: `{"status": "completed"}`

### POST `/api/gripper/open`

⚠️ **Moves hardware.** Opens the gripper. No request body.

Response: `{"status": "opened"}`

### POST `/api/gripper/close`

⚠️ **Moves hardware.** Closes the gripper. No request body.

Response: `{"status": "closed"}`

### POST `/api/gripper/dock`

⚠️ **Moves hardware.** Opens the gripper and drives it into its docked/recessed position. No request
body.

Response: `{"status": "docked", "g_target": <float>, "zg_target": <float>, "forced_plate_sensor": <bool>}`
— or `{"status": "aborted", "message": "…"}` when the operator aborts the task.

### POST `/api/pick_place`

⚠️ **Moves hardware.** Full gripper-based labware transfer: retract, open and nest the gripper,
travel to the source, grip, lift to a carry height, travel to the destination, release, and
re-nest. Intermediate poses are solved from teachpoints plus labware handling geometry.

Request body — `PickPlaceRequest`:

| Field | Type | Default |
|---|---|---|
| `from_location` | `int` | required |
| `to_location` | `int` | required |
| `speed` | `string \| null` | `MED` |

Response: `{"status": "completed", "from": <int>, "to": <int>, "diagnostics": {...}}` — `diagnostics`
carries the solved pick, carry, and place positions.

### POST `/api/execute_command`

⚠️ **Moves hardware.** Generic dispatcher: runs one named high-level task through a single request
shape. `command` is lower-cased and spaces become underscores.

Supported `command` values: `aspirate`, `dispense`, `mix`, `tips_on`, `tips_off`, `stack_plates`,
`destack_plate`, `mount_plates`, `unmount_plate`, `delid_plate`, `relid_plate`,
`scan_stack_height`, `read_barcode`.

Request body — `ExecuteCommandRequest`:

| Field | Type | Default | Used by |
|---|---|---|---|
| `command` | `string` | required | all |
| `location` | `int` | `1` | aspirate, dispense, mix, tips_on, tips_off, scan_stack_height, read_barcode |
| `source_location` | `int \| null` | `null` | stack_plates, destack_plate, mount_plates, unmount_plate |
| `base_location` | `int \| null` | `null` | stack_plates, mount_plates |
| `destination_location` | `int \| null` | `null` | destack_plate, unmount_plate |
| `lid_location` | `int \| null` | `null` | relid_plate |
| `plate_location` | `int \| null` | `null` | delid_plate, relid_plate |
| `lid_destination` | `int \| null` | `null` | delid_plate |
| `manual_count` | `int \| null` | `null` | scan_stack_height |
| `volume` | `float` | `0.0` | aspirate, dispense, mix |
| `pre_aspirate` | `float` | `0.0` | aspirate, mix |
| `post_aspirate` | `float` | `0.0` | aspirate |
| `distance_from_bottom` | `float` | `2.0` | aspirate, dispense, mix |
| `aspirate_distance` | `float \| null` | `null` | mix (falls back to `distance_from_bottom`) |
| `dispense_distance` | `float \| null` | `null` | mix (falls back to `distance_from_bottom`) |
| `dispense_at_different_distance` | `bool` | `false` | mix |
| `blowout` | `float` | `0.0` | dispense, mix |
| `empty_tips` | `bool` | `false` | dispense |
| `mix_cycles` | `int` | `3` | mix |
| `dynamic_tip_extension` | `float` | `0.0` | aspirate, mix |
| `dynamic_tip_retraction` | `float` | `0.0` | dispense |
| `tip_touch` | `bool` | `false` | aspirate, dispense, mix |
| `liquid_class` | `string \| null` | `null` | aspirate, dispense, mix |
| `pipette_technique` | `string \| null` | `null` | aspirate, dispense, mix |

Responses:

- `aspirate`, `dispense`, `mix`, `tips_on`, `tips_off` → `{"status": "completed", "command": "<command>"}`
- `stack_plates`, `destack_plate`, `mount_plates`, `unmount_plate`, `delid_plate`, `relid_plate`,
  `scan_stack_height`, `read_barcode` → the task's own result object is returned verbatim; see the
  corresponding `Bravo` method for the exact fields.
- Unknown command → HTTP `200` with `{"status": "error", "message": "Unknown command: <name>"}`

---

## Teachpoints

Teachpoints hold the reference X/Y/Z coordinates for each deck location and are the basis for every
location-driven task.

### GET `/api/teachpoint/{location}`

Reads the taught coordinates for one deck location.

| Path parameter | Type |
|---|---|
| `location` | `int` |

Response: `{"location": <int>, "teachpoint": {"x": <float>, "y": <float>, "z": <float>}}`, or
`{"location": <int>, "teachpoint": null}` when the location has never been taught.

### POST `/api/teachpoint/{location}`

Writes explicit X/Y/Z coordinates into the teachpoint store.

Path parameter: `location` (`int`). Request body — `TeachpointSetRequest`:
`{"x": <float>, "y": <float>, "z": <float>}`

Response: `{"status": "taught", "location": <int>}`

### POST `/api/teachpoint/{location}/teach_current`

Captures the robot's **current** X/Y/Z position as the teachpoint for a location. Requires a
connection (it reads live axis positions) and writes the resolved teach-tip fields back into the
active profile, saving it to disk.

Path parameter: `location` (`int`). Request body — `TeachCurrentRequest` (optional):

| Field | Type | Notes |
|---|---|---|
| `tip_capacity` | `float \| null` | Resolves a tip definition by capacity |
| `tip_id` | `string \| null` | Takes precedence over `tip_capacity` |

If neither is supplied, the profile's `teach_tip_capacity` / `default_tip_capacity` is used.

Response:

```json
{
  "status": "taught",
  "location": 4,
  "teach_tip_id": "...",
  "teach_tip_capacity": 200.0,
  "teach_tip_height_mm": 51.0,
  "teach_tip": {"tip_id": "...", "capacity_ul": 200.0, "label": "...",
                "length_mm": 51.0, "source": "...", "model_3d": "..."},
  "teachpoint": {"x": 0.0, "y": 0.0, "z": 0.0}
}
```

---

## Head & Tips

### GET `/api/head_mode`

Returns the active head-mode configuration — which subset of the head's barrels is considered
active for tip and liquid-handling operations.

Response: `{"head_type": "<HeadType name>", "head_mode": {...}}`

The `head_mode` object contains `subset_type`, `subset_config`, `row_count`, `column_count`,
`num_channels`, and `display_text`.

### PUT `/api/head_mode`

Updates the active head-mode configuration. Values are normalised against the installed head's
geometry, so out-of-range or unsupported combinations fall back to sane defaults rather than
erroring.

Request body — `HeadModeRequest`:

| Field | Type | Accepted values |
|---|---|---|
| `subset_type` | `string \| null` | `all_barrels`, `row`, `column`, `rectangle`, `single_barrel`, `quadrant` (normalised to `rectangle`) |
| `subset_config` | `string \| null` | `front_left`, `front_right`, `back_left`, `back_right` |
| `row_count` | `int \| null` | Used by `row` and `rectangle` |
| `column_count` | `int \| null` | Used by `column` and `rectangle` |

Response: `{"status": "updated", "head_type": "<HeadType name>", "head_mode": {...}}`

### GET `/api/head_mode/suggest`

Suggests a head mode for the labware currently assigned to a deck location, based on the installed
head and the labware's well count.

| Query parameter | Type |
|---|---|
| `location` | `int` |

Response: `{"location": <int>, "wells": <int|null>, "head_type": "<name>", "head_mode": {...}}`

### GET `/api/tipbox/legal_anchors`

Computes the anchor positions at which the given head mode can legally engage a tip box of the
given dimensions — i.e. placements where inactive barrels will not collide with tips. Used by the
designer's Tips On / Tips Off pickers.

| Query parameter | Type | Default | Notes |
|---|---|---|---|
| `subset_type` | `string` | `all_barrels` | |
| `subset_config` | `string` | `back_left` | |
| `row_count` | `int \| null` | `null` | |
| `column_count` | `int \| null` | `null` | |
| `tipbox_rows` | `int` | `8` | Must be positive |
| `tipbox_cols` | `int` | `12` | Must be positive |
| `purpose` | `string` | `pickup` | `pickup` or `return` |
| `occupied_cells` | `string \| null` | `null` | Comma-separated `row:col` pairs, e.g. `0:0,0:1,1:2` |

When `occupied_cells` is omitted, occupancy is inferred from `purpose`: `pickup` assumes a full box,
`return` assumes an empty one. Malformed tokens in `occupied_cells` are silently dropped.

Response:

```json
{"head_mode": {...}, "tipbox_rows": 8, "tipbox_cols": 12, "purpose": "pickup",
 "occupied_cells_count": 96, "legal_anchors": [{"row": 0, "col": 0, ...}, ...]}
```

Errors: `400` for an invalid head mode, non-positive box dimensions, or an unknown `purpose`.

### GET `/api/tip_selection`

Returns the current tip-selection anchor and the selection recorded for the tips presently on the
head.

Response: `{"tip_selection": {...} | null, "tips_on_head_selection": {...} | null}`

Each selection object carries `location`, `row`, `col`, `row_count`, `column_count`,
`mirror_corner`, `head_anchor`, `anchor_row`, `anchor_col`.

### PUT `/api/tip_selection`

Sets the anchor well used for partial tip pickup and return. The selection is validated against the
head mode, tip-box geometry, and accessibility rules.

Request body — `TipSelectionRequest`: `{"location": <int>, "row": <int>, "col": <int>}`

Response: `{"status": "updated", "tip_selection": {...}}`

### GET `/api/plate_selection`

Returns the current plate anchor for a location, the legal anchors, and the well footprint the head
would cover.

| Query parameter | Type |
|---|---|
| `location` | `int` |

Response: `{"location": <int>, "selection": {...} | null, "legal_anchors": [...], "footprint": [{"row": <int>, "col": <int>}, ...], "rows": <int>, "cols": <int>}`

### PUT `/api/plate_selection`

Sets the selected plate anchor well for a location.

Request body — `PlateSelectionRequest`: `{"location": <int>, "row": <int>, "col": <int>}`

Response: `{"status": "updated", "plate_selection": {...}, "legal_anchors": [...], "footprint": [...]}`

### GET `/api/tips`

Lists tip definitions.

| Query parameter | Type | Notes |
|---|---|---|
| `head_type` | `string \| null` | When set, returns only tips compatible with that head, in the head's option format |

Response: `{"tips": [...]}`

### POST `/tips`

Creates a tip definition.

Request body — `TipDefinitionRequest` (all fields optional; `None` values are dropped before the
store sees them):

| Field | Type |
|---|---|
| `tip_id` | `string` |
| `label` | `string` |
| `capacity_ul` | `float` |
| `length_mm` | `float` |
| `source` | `string` |
| `model_3d` | `string` |
| `compatible_heads` | `string[]` |

Response: `{"tip": {...}}`. Errors: `400` on invalid input.

### PATCH `/tips/{tip_id}`

Updates a tip definition. Path parameter `tip_id` (`string`); body — `TipDefinitionRequest`.

Response: `{"tip": {...}}`. Errors: `404` unknown tip, `400` invalid input.

### DELETE `/tips/{tip_id}`

**Destructive.** Deletes a tip definition.

Response: `{"status": "deleted", "tip_id": "<id>"}`. Errors: `404` unknown tip.

### POST `/api/change_head`

Changes the configured head type and resets the active head mode to the default full-head
configuration (`all_barrels` / `back_left`). If the controller supports it, the new head type is
pushed down to the controller as well.

Request body — `ChangeHeadRequest`: `{"head_type": "<HeadType name>"}`

Response: `{"status": "head_changed", "head_type": "<name>", "head_type_display": "<label>"}`

Errors: `400` for an unknown head type name.

---

## State & Diagnostics

### GET `/api/state`

Returns the consolidated runtime state used by the UI. This is the same payload broadcast over
`/ws/state`. Position and I/O fields are populated only while connected; during active motion the
server serves a cached snapshot rather than issuing live reads.

Key fields:

| Field | Type | Description |
|---|---|---|
| `connected` | `bool` | Transport is open |
| `initialized` | `bool` | Initialization has completed |
| `positions` | `{axis: float}` | Current engineering-unit positions |
| `head_type` | `string` | Installed head type name |
| `machine_id` | `string` | Machine identifier from the profile |
| `active_tip_id` | `string` | Resolved active tip definition |
| `active_tip_capacity_ul` | `float` | Capacity of the active tip |
| `head_mode` | `object` | Active head-mode configuration |
| `tips_on_head_mode` | `object \| null` | Head mode captured when tips were picked up |
| `tip_selection` | `object \| null` | Current tip anchor |
| `tips_on_head_selection` | `object \| null` | Anchor of the tips currently mounted |
| `plate_selection` | `{location: object}` | Per-location plate anchors |
| `controller_type` | `string` | Active controller type |
| `deck` | `{location: string[]}` | Labware names stacked at each location |
| `deck_details` | `{location: object[]}` | Full labware metadata plus `is_mounted` |
| `engine_busy` | `bool` | Task engine is running something |
| `motors_enabled` | `{axis: bool}` | Servo enable state per axis |
| `telemetry` | `object` | Controller-supplied telemetry |
| `head_attached` | `bool` | Head presence |
| `go_button_pressed` | `bool` | Front-panel button state |
| `plate_in_gripper` | `bool` | Resolved plate presence |
| `tips_on_head` | `bool` | Tips currently mounted |
| `tip_labware` | `string \| null` | Name of the tip-box labware in use |
| `tip_definition_id` | `string \| null` | Tip definition of the mounted tips |
| `attached_tip_length_mm` | `float \| null` | Length of the mounted tips |
| `tipbox_inventory` | `object` | Per-location tip occupancy |
| `robot_disabled` | `bool` | Safety/disable flag |
| `teachpoints` | `{location: {x, y, z}}` | Taught positions for locations 1–9 |
| `task_status` | `object` | Active task: `step`, `step_index`, `step_count`, `status`, optional `error` |

### GET `/api/positions`

Returns just the current axis positions.

Response: `{"X": <float>, "Y": <float>, "Z": <float>, "W": <float>, "G": <float>, "Zg": <float>}` —
axes that cannot be read are omitted.

### GET `/api/io_status`

Compact safety/I-O view derived from the full state.

Response: `{"robot_disabled": <bool>, "head_attached": <bool>, "head_type": "<string>", "go_button_pressed": <bool>, "plate_in_gripper": <bool>, "motors_enabled": {axis: bool}}`

### GET `/api/diagnostics`

Returns wire-level protocol diagnostics — command counts and the error log from the comm layer.
Only available on controllers that implement a diagnostics hook (currently `agile_7612`).

Response: the controller's diagnostics object, or
`{"error": "Diagnostics not available for this controller type"}` with HTTP `200` on other
controllers.

### GET `/api/accessories`

Lists configured accessories with their lazy-loaded driver runtime state.

Response: `{"devices": [{<device config fields>, "runtime": {"loaded": <bool>, "is_open": <bool>, "is_running": <bool>}}, ...]}`

### POST `/api/accessories/{accessory_id}/teleshake/start`

Starts a configured orbital shaker accessory. **Physically actuates the accessory** — make sure any
labware on the shaker is seated.

Path parameter: `accessory_id` (`string`). Request body — `TeleshakeActionRequest`:

| Field | Type | Notes |
|---|---|---|
| `rpm` | `int \| null` | Shake speed; driver default when omitted |
| `direction` | `string \| null` | Rotation direction; driver default when omitted |

Response: the driver's result object; see the handler. Errors: `400` when the accessory id is not
configured, `500` on driver failure.

### POST `/api/accessories/{accessory_id}/teleshake/stop`

Stops the shaker. Path parameter `accessory_id` (`string`); no body.

Response: the driver's result object. Errors: `400` unknown accessory, `500` driver failure.

---

## Vision

These endpoints proxy to a local vision service process (depth camera integration). **All of them
return `404` when `vision.enabled` is false in the active profile**, and `503` when the local
service is unreachable.

### GET `/api/vision/status`

Reports vision-service connectivity, camera SDK availability, and the saved calibration artifact.

Response: the service's `/status` payload.

### GET `/api/vision/calibration`

Returns the saved camera-to-deck calibration for the active machine.

Response: the service's `/calibration` payload.

### POST `/api/vision/calibration/run`

Starts the guided calibration workflow, or creates a calibration scaffold when hardware is not
ready. The active machine id is sent along automatically.

Request body — `VisionCalibrationRunRequest`: `{"notes": "<string|null>"}`

Response: the service's `/calibration/run` payload.

### POST `/api/vision/calibration/capture_baselines`

Captures a live depth reference for all 9 calibrated deck ROIs. Run with an **empty deck**, after
ROI calibration and before verification. No request body.

Response: the service's `/calibration/capture_baselines` payload.

### POST `/api/vision/verify`

Builds the expected deck scene from current deck assignments, teachpoints, head type, and tip-box
occupancy, sends it to the vision service, and returns a slot-by-slot comparison against what the
camera observes. No request body.

Response: the service's `/verify` payload — a report with per-slot expected labware, observed
status, and confidence.

### GET `/api/vision/preview`

Returns the latest camera preview image. Response body is raw bytes with the content type reported
by the vision service (typically `image/jpeg` or `image/png`).

### GET `/api/vision/preview/depth`

Returns the latest colorized depth preview image. Same response handling as `/api/vision/preview`.

### GET `/api/vision/detect`

*Excluded from the OpenAPI schema.* Fetches the service's live detection report and decorates each
slot with the labware pyBravo expects there, adding `expected_labware` and a `display_label` to
every slot entry.

Response: the service's `/detect` payload with the added per-slot fields.

### GET `/api/vision/stream`

*Excluded from the OpenAPI schema.* Issues a `307` redirect to the vision service's MJPEG stream
URL.

### GET `/api/vision/stream/depth`

*Excluded from the OpenAPI schema.* `307` redirect to the depth stream URL.

### POST `/api/vision/calibration/roi/start`

Launches the interactive ROI calibration tool in a separate console window, against the reference
image recorded in the saved calibration. Windows-oriented — it shells out via `cmd /c start`.

| Query parameter | Type | Notes |
|---|---|---|
| `location` | `int \| null` | When set, must be 1–9; restricts calibration to one deck slot |

Response: `{"status": "starting", "reference_image_path": "<path>", "location": <int|null>, "command": [<argv>]}`

Errors: `400` when no reference image exists yet or `location` is out of range, `404` when the
recorded reference image is missing on disk, `503` when the service is unreachable.

### POST `/api/vision/service/start`

Starts the local vision service in a separate process using the repository launcher script, passing
the profile's vision settings through the environment. Returns immediately so the caller can poll
for readiness. No request body.

Response: `{"status": "already_running", "service": {...}}` when the service already answers, else
`{"status": "starting", "command": "<script path>", "python": "<interpreter>", "service_url": "<url>", "sdk_root": "<path>"}`

Errors: `400` on non-Windows hosts, `404` when the launcher script is missing.

---

## Labware

### GET `/api/labware`

Lists the runtime labware catalog, normalised and summarised.

Response: `{"labware": [<definition summary>, ...]}`

### GET `/labware/types`

Lists editable labware type definitions from the labware editor store.

Response: `{"labware_types": [...]}`

### POST `/labware/types`

Creates a labware type and refreshes the runtime catalog.

Request body — `LabwareTypeRequest` (all fields optional; `None` values are dropped):

| Field | Type |
|---|---|
| `kind` | `string` |
| `name` | `string` |
| `vendor` | `string` |
| `catalog_number` | `string` |
| `description` | `string` |
| `base_class` | `string` |
| `wells` | `int` |
| `plate_dimensions_mm` | `object` |
| `plate_properties` | `object` |
| `well_dimensions_mm` | `object` |
| `pf400` | `object` |
| `planar_motor` | `object` |
| `labware_class_ids` | `string[]` |
| `tip_definition_id` | `string` |
| `supported_tip_ids` | `string[]` |

Response: `{"labware_type": {...}}`. Errors: `400` on invalid input.

### PATCH `/labware/types/{labware_type_id}`

Updates a labware type, refreshes the runtime catalog, and refreshes any live instances of that
type currently on the deck.

Path parameter: `labware_type_id` (`string`). Body — `LabwareTypeRequest`.

Response: `{"labware_type": {...}}`. Errors: `404` unknown type, `400` invalid input.

### DELETE `/labware/types/{labware_type_id}`

**Destructive.** Deletes a labware type and refreshes the runtime catalog.

Response: `{"status": "deleted", "labware_type_id": "<id>"}`. Errors: `404` unknown type.

### POST `/labware/types/{labware_type_id}/assets/image`

Uploads a 2D image asset for a labware type.

Path parameter: `labware_type_id` (`string`). Body: `multipart/form-data` with a `file` field.

Response: `{"labware_type": {...}}` (the updated definition). Errors: `404` unknown type, `400` when
`file` is missing or invalid.

### POST `/labware/types/{labware_type_id}/assets/model`

Uploads a 3D model asset for a labware type and refreshes the runtime catalog.

Path parameter: `labware_type_id` (`string`). Body: `multipart/form-data` with a `file` field.

Response: `{"labware_type": {...}}`. Errors: `404` unknown type, `400` invalid upload.

### GET `/labware/classes`

Lists editable labware classes, used to group compatible labware entries.

Response: `{"labware_classes": [...]}`

### POST `/labware/classes`

Creates a labware class.

Request body — `LabwareClassRequest`: `{"name": "<string|null>", "description": "<string|null>"}`

Response: `{"labware_class": {...}}`. Errors: `400` on invalid input.

### PATCH `/labware/classes/{labware_class_id}`

Updates a labware class name or description. Path parameter `labware_class_id` (`string`); body —
`LabwareClassRequest`.

Response: `{"labware_class": {...}}`. Errors: `404` unknown class, `400` invalid input.

### DELETE `/labware/classes/{labware_class_id}`

**Destructive.** Deletes a labware class and removes its membership references from labware entries.

Response: `{"status": "deleted", "labware_class_id": "<id>"}`. Errors: `404` unknown class.

---

## Liquid Classes & Pipette Techniques

### GET `/api/liquid_context`

Returns the active liquid-handling context — the machine, head, and tip combination used to resolve
liquid classes.

Response: `{"machine_id": "<string>", "head_type": "<string>", "tip_id": "<string>", "tip_capacity_ul": <float>}`

### GET `/api/liquid_classes`

Lists liquid classes. By default only classes that strictly match the current (or explicitly
requested) machine/head/tip context are returned, so the designer cannot offer a class that would
fail at execution.

| Query parameter | Type | Default | Notes |
|---|---|---|---|
| `machine_id` | `string \| null` | active context | |
| `head_type` | `string \| null` | active context | |
| `tip_id` | `string \| null` | see below | |
| `tip_capacity_ul` | `float \| null` | see below | |
| `all` | `bool` | `false` | `true` returns the entire catalog, unfiltered |

Tip narrowing follows the physical head state: with tips on, results are restricted to the loaded
tip; with tips off, every class for the machine and head is listed. An explicit `tip_id` or
`tip_capacity_ul` overrides that regardless of head state. `machine_id` and `head_type` filters are
never dropped. If a tip-capacity-filtered query returns nothing, the query is retried once without
the capacity constraint.

Response:

```json
{"context": {"machine_id": "...", "head_type": "...", "tip_id": "...",
             "tip_capacity_ul": 200.0, "tips_on": false},
 "liquid_classes": [...]}
```

With `all=true` the `context` block is the unmodified active context (no `tips_on` field).

### POST `/liquid-classes`

Creates a liquid class.

Request body — `LiquidClassRequest` (all fields optional; `None` values are dropped):

| Field | Type |
|---|---|
| `name` | `string` |
| `description` | `string` |
| `machine_id` | `string` |
| `head_type` | `string` |
| `tip_id` | `string` |
| `tip_capacity_ul` | `float` |
| `aspirate` | `object` |
| `dispense` | `object` |
| `equation` | `object` |

Response: `{"liquid_class": {...}}`. Errors: `400` on invalid input.

### PATCH `/liquid-classes/{liquid_class_id}`

Updates a liquid class. Path parameter `liquid_class_id` (`string`); body — `LiquidClassRequest`.

Response: `{"liquid_class": {...}}`. Errors: `404` unknown class, `400` invalid input.

### DELETE `/liquid-classes/{liquid_class_id}`

**Destructive.** Deletes a liquid class.

Response: `{"status": "deleted", "liquid_class_id": "<id>"}`. Errors: `404` unknown class.

### GET `/api/pipette_techniques`

Lists saved pipette techniques — reusable motion patterns layered onto aspirate and dispense.

Response: `{"pipette_techniques": [...]}`

### POST `/pipette-techniques`

Creates a pipette technique.

Request body — `PipetteTechniqueRequest` (all fields optional):

| Field | Type |
|---|---|
| `name` | `string` |
| `description` | `string` |
| `motion_type` | `string` |
| `radius_mm` | `float` |
| `segments` | `int` |
| `clockwise` | `bool` |
| `apply_on_aspirate` | `bool` |
| `apply_on_dispense` | `bool` |
| `z_phase` | `string` |

Response: `{"pipette_technique": {...}}`. Errors: `400` on invalid input.

### PATCH `/pipette-techniques/{technique_id}`

Updates a pipette technique. Path parameter `technique_id` (`string`); body —
`PipetteTechniqueRequest`.

Response: `{"pipette_technique": {...}}`. Errors: `404` unknown technique, `400` invalid input.

### DELETE `/pipette-techniques/{technique_id}`

**Destructive.** Deletes a pipette technique.

Response: `{"status": "deleted", "technique_id": "<id>"}`. Errors: `404` unknown technique.

---

## Deck

Deck assignment tells the software what is physically present at each location. Motion planning,
visualization, and compatibility checks all depend on it being accurate.

### PUT `/api/deck/{location}/labware`

Assigns labware to a deck location.

Path parameter: `location` (`int`). Request body — `DeckLabwareRequest`:

| Field | Type | Default | Notes |
|---|---|---|---|
| `labware_id` | `string` | required | Catalog id of the labware |
| `is_lidded` | `bool` | `false` | |
| `is_sealed` | `bool` | `false` | |
| `tip_definition_id` | `string \| null` | `null` | Tip boxes only |
| `tipbox_fill_state` | `string \| null` | `null` | Tip boxes only |

Response: `{"status": "assigned", "location": <int>, "labware": {<metadata>}}`

Errors: `400` for an unknown labware id or an invalid assignment.

### DELETE `/api/deck/{location}/labware`

**Destructive** to the software model (nothing moves): clears the labware assignment at a location.

Path parameter: `location` (`int`).

Response: `{"status": "cleared", "location": <int>}`. Errors: `400` on an invalid location.

---

## Profiles

Profiles are YAML files in the profile directory (`PYBRAVO_PROFILE_DIR`, default `./profiles`). The
active profile name is persisted in a `.active_profile` marker so it survives restarts.

### GET `/api/profiles`

Lists available profile names and the currently active one.

Response: `{"profiles": ["<name>", ...], "current": "<name>" | null}` — empty list when no profile
directory is configured.

### GET `/api/profile`

Returns the active profile.

Response:

```json
{
  "name": "...",
  "connection": {"controller_type": "...", "use_ethernet": true, "address": "...",
                 "serial_port": "...", "machine_id": "..."},
  "head": {"head_type": "...", "check_on_init": true, "default_tip_id": "...",
           "teach_tip_id": "...", "default_tip_capacity": 200.0,
           "teach_tip_capacity": 200.0, "teach_tip_length_mm": 51.0,
           "teach_tip_options": [...]},
  "safety": {"approach_height": 0.0, "z_safe_position": 0.0,
             "always_move_to_safe_z": true, "run_medium_speed": false,
             "prompt_home_w": false, "ignore_plate_sensor": false,
             "enable_tips_off_tip_touch": false, "is_srt": false},
  "vision": {"enabled": false, "service_url": "...", "sdk_root": "..."},
  "accessories": {...}
}
```

### PATCH `/api/profile`

Updates the active profile in place and saves it to disk. Only the fields present in the body are
applied. Changing `head_type` also resets `default_tip_id` and `teach_tip_id` to the new head's
defaults; changing accessories reinitialises the accessory drivers.

Request body — `ProfileUpdateRequest` (every field optional):

| Field | Type | Maps to |
|---|---|---|
| `approach_height` | `float` | `safety.approach_height` |
| `z_safe_position` | `float` | `safety.z_safe_position` |
| `always_safe_z` | `bool` | `safety.always_move_to_safe_z` |
| `run_medium_speed` | `bool` | `safety.run_medium_speed` |
| `prompt_home_w` | `bool` | `safety.prompt_home_w` |
| `ignore_plate_sensor` | `bool` | `safety.ignore_plate_sensor` |
| `enable_tips_off_tip_touch` | `bool` | `safety.enable_tips_off_tip_touch` |
| `is_srt` | `bool` | `safety.is_srt` |
| `controller_type` | `string` | `connection.controller_type` |
| `use_ethernet` | `bool` | `connection.use_ethernet` |
| `serial_port` | `string` | `connection.serial_port` |
| `address` | `string` | `connection.address` |
| `machine_id` | `string` | `connection.machine_id` |
| `head_type` | `string` | `head.head_type` (unknown names are logged and ignored) |
| `check_on_init` | `bool` | `head.check_on_init` |
| `teach_tip_capacity` | `float` | `head.teach_tip_capacity` |
| `teach_tip_id` | `string` | `head.teach_tip_id` |
| `vision_enabled` | `bool` | `vision.enabled` |
| `vision_service_url` | `string` | `vision.service_url` |
| `vision_sdk_root` | `string` | `vision.sdk_root` |
| `accessories` | `object` | Replaces the whole accessories config |
| `barcode_reader_enabled` | `bool` | `accessories.barcode_reader.enabled` |
| `barcode_reader_device_type` | `string` | `accessories.barcode_reader.device_type` |
| `barcode_reader_port` | `string` | `accessories.barcode_reader.port` |
| `barcode_reader_side` | `string` | `accessories.barcode_reader.side` |
| `barcode_reader_location` | `int` | `accessories.barcode_reader.location` |

Response: `{"status": "updated", "saved": <bool>}` — `saved` is `false` if the write to disk failed
or no profile path is configured.

### POST `/api/profile/load`

Loads a different profile from disk, replacing the in-memory profile, teachpoints, accessories, and
resetting head mode to `all_barrels` / `back_left`. Updates the `.active_profile` marker.

Request body — `ProfileLoadRequest`: `{"name": "<profile name>"}`

Response: `{"status": "loaded", "name": "<name>"}`

Errors: `409` if the robot is still connected (disconnect first), `400` if the profile directory is
unavailable, `404` if the named profile does not exist.

### POST `/api/profile/duplicate`

Copies a profile YAML to a new name. Does not change the active profile.

Request body — `ProfileDuplicateRequest`:

| Field | Type | Notes |
|---|---|---|
| `new_name` | `string` | Required; must not contain path separators, `.`, or `..` |
| `source` | `string \| null` | Defaults to the currently active profile |

Response: `{"status": "duplicated", "source": "<name>", "name": "<new name>"}`

Errors: `400` invalid/empty name or no profile directory, `404` source not found, `409` destination
already exists.

### POST `/api/profile/rename`

**Destructive.** Renames a profile YAML on disk. If the renamed profile is the active one, the
in-memory path and the `.active_profile` marker are updated.

Request body — `ProfileRenameRequest`: `{"old_name": "<string>", "new_name": "<string>"}`

Response: `{"status": "renamed", "old_name": "...", "new_name": "...", "was_active": <bool>}`

Errors: `400` invalid names or identical names, `404` source not found, `409` destination exists or
the active profile is still connected.

### POST `/api/profile/import_reg`

Imports a Windows registry profile export (`.reg` text) and either previews the parsed result or
saves it as a new profile. The response includes warnings for fields that need manual review —
notably the registry's head-type and tip-id enumerations, which are not mapped automatically.

Request body — `ProfileImportRegRequest`:

| Field | Type | Default | Notes |
|---|---|---|---|
| `content` | `string` | required | Raw registry-export text, already decoded by the client |
| `save_as` | `string \| null` | `null` | Omit to preview only |
| `overwrite` | `bool` | `false` | Allow replacing an existing profile |

Response:

```json
{"parsed_name": "...", "warnings": ["..."], "axes": ["X", "Y", ...],
 "teachpoint_locations": [1, 2, ...], "status": "previewed"}
```

When `save_as` is supplied, `status` is `"saved"` and a `name` field is added.

Errors: `400` unparsable payload / invalid name / no profile directory, `409` name exists and
`overwrite` is false, `500` write failure.

### POST `/api/profile/import_dat`

Imports a legacy `.dat` profile directory export (the pre-registry format). The top-level folder
name becomes the profile name; each subdirectory's `<folder>/<folder>.dat` file holds that sub-key's
key/value lines. The payload is converted to the registry document form and run through the same
importer, so mapping and warnings behave identically to `/api/profile/import_reg`.

Request body — `ProfileImportDatRequest`:

| Field | Type | Notes |
|---|---|---|
| `profile_name` | `string` | Top-level folder name |
| `files` | `ProfileImportDatFile[]` | Each `{"relative_path": "96LT/Axes/X/X.dat", "content": "<text>"}`, forward-slash separated |
| `save_as` | `string \| null` | Omit to preview only |
| `overwrite` | `bool` | Default `false` |

Response and errors: same shape as `/api/profile/import_reg`; additionally `400` when `files` is
empty.

---

## Device Discovery

### POST `/api/discover_devices`

Scans the local network for Bravo devices. Three probes run concurrently and their results are
merged by IP: a UDP broadcast discovery handshake, a TCP subnet sweep (Darwin port first, then the
Agile port with a protocol ping), and a directed probe of the address already stored in the profile.
Subnets larger than `/22` are skipped. In simulation mode a single clearly-labelled virtual device
is returned instead.

Request body — `DiscoverDevicesRequest`:

| Field | Type | Default | Notes |
|---|---|---|---|
| `adapter` | `string` | `"All interfaces"` | An adapter IP to scan from, or the sentinel to scan all |
| `controller_type` | `string \| null` | `null` | Falls back to the profile's controller type |

Response:

```json
{"devices": [{"device_id": "...", "device_type": "...", "ip_address": "192.168.1.50",
              "mac_address": "...", "status": "Matched" | "Found",
              "controller_type": "agile_7612"}],
 "adapters": [{"name": "...", "ip": "..."}]}
```

Devices whose IP matches the profile's configured address are marked `Matched` and sorted first.

### POST `/api/select_device`

Stores a discovered device's address (and optionally controller type) into the active profile and
saves it to disk. Setting an IP also sets `use_ethernet: true`.

Request body — `SelectDeviceRequest`:

| Field | Type | Default |
|---|---|---|
| `device_id` | `string` | `""` |
| `ip_address` | `string` | `""` |
| `controller_type` | `string \| null` | `null` |

Response: `{"status": "selected", "device_id": "...", "ip_address": "...", "controller_type": "..."}`

---

## Workflows

Workflows are node graphs persisted as JSON files. See `pybravo/workflow/models.py` for the
canonical shapes:

- **`WorkflowDefinition`** — `id`, `name`, `description`, `created`, `modified`,
  `deck: {location: WorkflowDeckEntry}`, `graph: object`
- **`WorkflowDeckEntry`** — `labware_id`, `name`, `kind`, `base_class`, `wells`, `is_lidded`,
  `is_sealed`, `tip_definition_id`
- **`WorkflowNodeConfig`** — `id`, `type`, `pos`, `properties`, `inputs`, `outputs`
- **`WorkflowExecutionRequest`** — `mode` (`simulate` \| `execute`), `speed`
- **`ExecutionMode`** — `simulate`, `execute`

Note that the CRUD endpoints below accept and return raw JSON objects rather than validating
against `WorkflowDefinition`; the models describe the shape the designer produces.

### GET `/api/workflows`

Lists summary metadata for every saved workflow.

Response: `{"workflows": [{"id": "...", "name": "...", "description": "...", "created": "...", "modified": "..."}, ...]}`

### GET `/api/workflows/{workflow_id}`

Loads one workflow by id.

Response: the full stored workflow object. Errors: `404` when not found.

### POST `/api/workflows`

Creates a workflow. The body is an arbitrary JSON object (a `WorkflowDefinition`-shaped payload);
an `id` and `created`/`modified` timestamps are assigned if absent.

Response: the stored workflow object, including its assigned `id`.

### PUT `/api/workflows/{workflow_id}`

Updates an existing workflow. The body is merged over the stored object; `id` is preserved and
`modified` is refreshed.

Response: the updated workflow object. Errors: `404` when not found.

### DELETE `/api/workflows/{workflow_id}`

**Destructive.** Deletes the workflow file.

Response: `{"status": "deleted"}`. Errors: `404` when not found.

### POST `/api/workflows/import-json`

Imports a workflow from an uploaded JSON file. A fresh `id` is assigned to avoid collisions.

Body: `multipart/form-data` with a `file` field.

Response: the stored workflow object. Errors: `400` on malformed JSON or a non-object payload.

### GET `/api/workflows/{workflow_id}/export`

Exports a workflow as a downloadable JSON file.

Response: `application/json` with `Content-Disposition: attachment; filename="<workflow_id>.json"`.
Errors: `404` when not found.

### POST `/api/workflows/{workflow_id}/simulate`

Runs a workflow in simulation mode against a fresh simulation-mode Bravo that reuses the active
profile, so calibrated teachpoints drive the 3D viewport. A snapshot of the live runtime selection
state is applied so subset geometry matches the main UI. **No hardware motion.**

Execution is asynchronous: the endpoint returns as soon as the run starts, and progress arrives as
`workflow:*` events on `/ws/state`.

Response: `{"status": "started", "workflow_id": "<id>", "mode": "simulate"}`

Errors: `404` unknown workflow; `400` with a structured detail when pre-flight validation finds
unresolvable liquid-class or pipette-technique references:

```json
{"detail": {"message": "Workflow has 2 invalid reference(s) …",
            "invalid_nodes": [{"node_id": 4, "node_type": "liquid/Aspirate",
                               "node_title": "...", "field": "liquid_class",
                               "value": "...", "reason": "..."}]}}
```

### POST `/api/workflows/{workflow_id}/execute`

⚠️ **Moves hardware — runs an entire workflow graph on the physical robot.** Every task node
dispatches against the live connection. If the controller has not been initialized yet, the server
initializes it first (which homes the machine). Same asynchronous model and `workflow:*` event
stream as `/simulate`.

Response: `{"status": "started", "workflow_id": "<id>", "mode": "execute"}`

Errors: `404` unknown workflow; `409` when no Bravo exists, the Bravo is not connected, the profile
is configured for the `simulation` controller, or initialization fails; `400` with the same
validation-detail shape as `/simulate`.

### POST `/api/workflows/stop`

Aborts the running simulation or execution. No request body.

⚠️ Aborting mid-execution leaves the robot wherever the current step stopped — inspect the deck
before resuming.

Response: `{"status": "stopped"}`, or `{"status": "no_workflow_running"}` when nothing is active.

### POST `/api/script_action`

Resolves a paused script-error prompt raised by a Script node.

Request body — `ScriptActionRequest`:

| Field | Type | Default | Notes |
|---|---|---|---|
| `action` | `string` | required | `retry`, `edit_retry`, or `abort` |
| `new_source` | `string` | `""` | Replacement script text for `edit_retry` |

Response: `{"accepted": <bool>, "action": "<action>"}`, or
`{"accepted": false, "reason": "no_workflow_running"}`.

⚠️ Choosing `retry` or `edit_retry` resumes execution, which resumes motion on a live run.

### GET `/api/script_snippets`

Returns the script-snippet registry backing the designer's "Insert snippet" menu.

Response: `{"snippets": [...]}`

### POST `/api/user_prompt_response`

Resolves a paused `prompt_user()` call inside a Script node, unblocking the sandboxed script thread.

Request body — `UserPromptResponse`:

| Field | Type | Default |
|---|---|---|
| `request_id` | `string` | required |
| `value` | `string` | `""` |
| `cancelled` | `bool` | `false` |

Response: `{"accepted": <bool>, "request_id": "<id>"}`, or
`{"accepted": false, "reason": "no_workflow_running"}`.

⚠️ Answering a prompt resumes execution, which resumes motion on a live run.

### POST `/api/workflow/import`

Imports a legacy XML protocol file (`.pro`) and returns the parsed workflow. The upload is written
to a temporary file, parsed, and the temp file is removed. Nothing is persisted — the caller decides
whether to save the result via `POST /api/workflows`.

Body: `multipart/form-data` with a `file` field.

Response: `{"workflow": {...}}`. Errors: `400` when the file cannot be parsed.

---

## Workflow Drafting (LLM)

These endpoints generate draft workflows from natural language or from scientific-paper PDFs. They
depend on optional services: an LLM provider (credentials via environment/`.env`) and a
document-parsing service configured through `PYBRAVO_DOCLING_URL`.

Shared error mapping:

| Status | Meaning |
|---|---|
| `501` | A required dependency or configuration is missing on this server |
| `502` | An upstream call (LLM or document parser) failed |
| `503` | No LLM credentials are available |
| `500` | Parsing failed for another reason |

None of these endpoints move hardware.

### POST `/api/workflow/draft`

Generates a draft workflow from a natural-language prompt, optionally grounded in the deck currently
loaded in the designer so the model reuses exact `labware_id` values. The draft is recorded with a
`session_id` for later diffing against the user's edits.

Request body — `WorkflowDraftRequest`:

| Field | Type | Notes |
|---|---|---|
| `prompt` | `string` | Required, must be non-empty |
| `deck` | `object \| null` | The designer tab's current deck configuration |

Response:

```json
{"workflow": {...}, "warnings": ["..."], "errors": ["..."],
 "meta": {"provider": "...", "model": "...", "attempts": 1},
 "session_id": "..."}
```

Errors: `400` empty prompt, plus the shared 501/502/503 mapping.

### POST `/api/workflow/parse_pdf`

Parses a PDF through the configured document-parsing service and returns its structured content. It
does **not** draft a workflow — use it to inspect what a later drafting pass will see.

Body: `multipart/form-data` with a `file` field (must end in `.pdf` and be non-empty).

Response:

```json
{"source_name": "paper.pdf", "page_count": 8,
 "markdown_preview": "<first 2000 chars>", "markdown_length": 45123,
 "paragraph_count": 312, "sections_detected": {"methods": 47, ...},
 "methods_paragraphs": [{"id": "p-134", "text": "...", "page": 4, "kind": "paragraph"}]}
```

Errors: `400` non-PDF or empty upload, plus the shared mapping.

### POST `/api/workflow/draft_from_pdf`

End-to-end draft from a paper: parse the PDF, extract grounded facts from the methods text, convert
those facts into a workflow where each non-structural node carries a citation back to its source
paragraph, then validate citation coverage and graph sanity. Parsed papers are content-addressed and
cached, so repeat uploads skip the parsing step.

Body: `multipart/form-data` with a `file` field.

| Query parameter | Type | Default | Notes |
|---|---|---|---|
| `include_deck` | `bool` | `true` | Accepted but currently unused — this endpoint runs without live deck context |

Response: the `/api/workflow/draft` payload, plus:

| Field | Type | Description |
|---|---|---|
| `facts` | `object[]` | Extracted grounded facts, each tagged with its source paragraph |
| `summary` | `string` | Model-written summary of the extracted protocol |
| `paragraph_excerpts` | `{paragraph_id: {text, page, section}}` | Excerpts (≤500 chars) for every cited paragraph |
| `source_file` | `string` | Original filename |
| `page_count` | `int` | |
| `session_id` | `string` | For later `.../patch` calls |
| `pdf_hash` | `string` | SHA-256 of the uploaded bytes |
| `paper_history` | `object` | Prior uploads of this same PDF |

Errors: `400` non-PDF or empty upload, plus the shared mapping.

### POST `/api/workflow/segment_paper`

First pass of the picker flow: parse a PDF and return candidate protocols found within it, sorted by
confidence, so the operator can choose which one to draft.

Body: `multipart/form-data` with a `file` field, plus a `refine_with_llm` form field
(`bool`, default `true`).

Response:

```json
{"pdf_hash": "sha256…", "source_file": "paper.pdf", "page_count": 16,
 "paper_history": {...}, "candidates": [{...}], "autoselect_idx": null, "notes": ""}
```

`autoselect_idx` is a non-null index when one candidate is confident enough to skip the picker.

Errors: `400` non-PDF or empty upload, `500` when segmentation fails, plus the shared mapping.

### POST `/api/workflow/draft_from_analyzed`

Drafts a workflow from a user-selected subset of a previously segmented paper's paragraphs. Requires
a prior `POST /api/workflow/segment_paper` call so the parsed paper is cached.

Request body — `DraftFromAnalyzedRequest`:

| Field | Type | Default | Notes |
|---|---|---|---|
| `pdf_hash` | `string` | required | From `segment_paper` |
| `selected_paragraph_ids` | `string[]` | required | Paragraphs to draft from |
| `selected_candidate_title` | `string` | `""` | Bookkeeping only |
| `candidates_presented` | `object[] \| null` | `null` | Picker telemetry |
| `deck` | `object \| null` | `null` | Current deck context |
| `time_on_picker_s` | `float \| null` | `null` | Picker telemetry |

Response: the same shape as `/api/workflow/draft_from_pdf` (minus `paper_history`), including
`facts`, `summary`, `paragraph_excerpts`, `source_file`, `page_count`, `pdf_hash`, and a new
`session_id`.

Errors: `404` when the PDF has not been analyzed yet, plus the shared mapping.

### POST `/api/workflow/draft/{session_id}/patch`

Records a user-edited workflow against the frozen as-drafted snapshot, computing a structural diff.
Called by the designer on save, save-as, simulate, and execute of a drafted tab. Primarily a
side-effecting call.

Path parameter: `session_id` (`string`). Request body — `DraftPatchRequest`:

| Field | Type | Default | Notes |
|---|---|---|---|
| `workflow` | `object` | required | The current workflow JSON |
| `trigger` | `string` | `"save"` | `save`, `save_as`, `execute`, or `simulate` |
| `workflow_id_saved_as` | `string \| null` | `null` | Set on save-as |

Response: `{"recorded": true, "diff_summary": {...}}`, or `{"recorded": false, "reason": "unknown_session"}`
(HTTP `200`) when the session id is not recognised — for example on a workflow that predates the
drafter.

### GET `/api/drafter/status`

Diagnostic: whether the drafter's persistence layer is configured and reachable.

Response:

```json
{"mongo_configured": true, "mongo_reachable": true, "mongo_db": "...",
 "pdf_cache_dir": "...", "pdf_count": 12, "local_store_dir": "...",
 "parsed_papers_in_memory": 3, "node_property_defaults": {...}}
```

### GET `/api/drafter/debug`

Per-collection counts, sampled last rows, and index lists. Large fields (markdown, raw document,
drafted/final workflows) are replaced with `<type len=N>` placeholders so the response stays small.

Returns an object; see `pybravo/workflow/drafter/store.py::debug_snapshot`.

### GET `/api/drafter/dashboard`

JSON aggregates backing the `/drafter-dashboard` page.

| Query parameter | Type | Default | Notes |
|---|---|---|---|
| `days` | `int` | `30` | Clamped to 1–365; controls the drafts-per-day window only |

Returns an object; see `pybravo/workflow/drafter/store.py::dashboard_aggregates`.

### GET `/api/drafter/paper/{pdf_hash}/page/{page_no}.png`

Renders one page of a cached PDF as a PNG. Rendered pages are cached next to the PDF, so only the
first request pays the render cost.

| Parameter | In | Type | Default |
|---|---|---|---|
| `pdf_hash` | path | `string` (SHA-256) | — |
| `page_no` | path | `int` (1-indexed) | — |
| `scale` | query | `float` | `1.5` |

Response: `image/png`. Errors: `404` when the PDF is not cached or the page is out of range.

### GET `/api/drafter/paper/{pdf_hash}/paragraphs`

Returns the full paragraph list for a previously analyzed PDF, so the picker can show body text and
page numbers without re-parsing.

Path parameter: `pdf_hash` (`string`).

Response: `{"pdf_hash": "...", "source_file": "...", "page_count": <int>, "paragraphs": [...]}`

Errors: `404` when the PDF is not cached.

---

## HTML pages and static mounts

These routes serve the browser UI. All are `GET`, return `text/html`, and are excluded from the
OpenAPI schema (`include_in_schema=False`).

| Path | Serves |
|---|---|
| `/labware-editor` | Labware editor — the React dashboard source is inlined into a standalone HTML page |
| `/liquid-class-editor` | `frontend/liquid_class_editor.html` |
| `/tip-editor` | `frontend/tip_editor.html` |
| `/workflow` | `frontend/workflow_editor.html` |
| `/designer` | `frontend/designer.html`, served with `no-store` cache headers |
| `/drafter-dashboard` | `frontend/drafter_dashboard.html` |
| `/vision-calibration` | `frontend/vision_calibration.html` |
| `/` | `index.html` from the configured static directory — registered only when `run_server(static_dir=…)` is given |

Each file-backed page returns `404` when the source file is missing.

### Static mounts

Mounted at startup inside `run_server()`:

| Mount | Directory | Condition |
|---|---|---|
| `/labware-assets` | The labware editor's asset directory | Always |
| `/model` | `pybravo/model` | Only with `static_dir`, and only if the directory exists |
| `/labware` | `<repo>/labware` | Only with `static_dir`, and only if the directory exists |
| `/static` | The configured static directory (HTML mode enabled) | Only with `static_dir` |

The `/labware` mount is registered after the `/labware/types` and `/labware/classes` API routes, so
those routes continue to take precedence.

---

## WebSocket: `/ws/state`

`ws://localhost:8000/ws/state`

On connect, the socket is accepted and registered with the server's connection manager. The server
then pushes state frames in a loop; the client is not required to send anything.

### State frames

While the robot is connected, each tick sends the **exact same JSON object returned by
`GET /api/state`** — see [that section](#get-apistate) for the full field list. When the robot is
not connected, the loop still runs but sends nothing, so an idle disconnected client sees no
traffic.

### Poll and throttle rates

| Controller type | Interval | Approximate rate |
|---|---|---|
| `darwin`, `darwin_native`, `agile`, `agile_7612` | `0.2 s` | 5 Hz |
| Everything else (including `simulation`) | `1/30 s` | 30 Hz |

Real controllers are throttled to 5 Hz because each state frame costs real protocol reads.

### Workflow event frames

The same socket is used as a broadcast channel by the workflow executor. While a workflow is
simulating or executing, additional JSON messages are pushed to every connected client. These are
distinguished from state frames by a `type` field beginning with `workflow:`. Observed event types
include:

`workflow:start`, `workflow:complete`, `workflow:error`, `workflow:node_start`,
`workflow:node_step`, `workflow:node_complete`, `workflow:branch`, `workflow:positions`,
`workflow:runtime_state`, `workflow:vars_update`, `workflow:script_result`,
`workflow:script_error`, `workflow:user_prompt`, `workflow:task_warning`,
`workflow:task_aborted`, `workflow:barcode_read`, `workflow:plate_pick`.

Clients should branch on the presence of `type`: messages with a `workflow:` type are execution
events, and messages without one are full state snapshots.

Broadcast is best-effort — a send failure on one client is swallowed and does not affect the others.

---

## Route inventory

127 HTTP routes and 1 WebSocket endpoint are declared in `pybravo/web/server.py`:

| Method | Count |
|---|---|
| `GET` | 44 |
| `POST` | 65 |
| `PUT` | 5 |
| `PATCH` | 6 |
| `DELETE` | 7 |
| `WEBSOCKET` | 1 |
| **Total** | **128** |

The `GET /` route is included in the `GET` count but is only registered when the server is started
with a static directory.

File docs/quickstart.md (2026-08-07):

# Quickstart

Your first fifteen minutes with pyBravo: start the server, tour the browser
UI, and drive a simulated Bravo through a home, a jog, and a complete
aspirate/dispense cycle — with no hardware attached.

Everything on this page runs against the built-in simulation. Nothing moves in
the physical world. When you are ready for a real instrument, jump to
[Moving to real hardware](#moving-to-real-hardware) at the end.

**Before you start:** you need a working install. See
[installation](installation.md).

Each step below says what *should* happen, so you can tell whether it worked
before moving on. Where a step is easier in the browser, the equivalent HTTP
call is given too — the UI and the API do exactly the same thing.

---
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

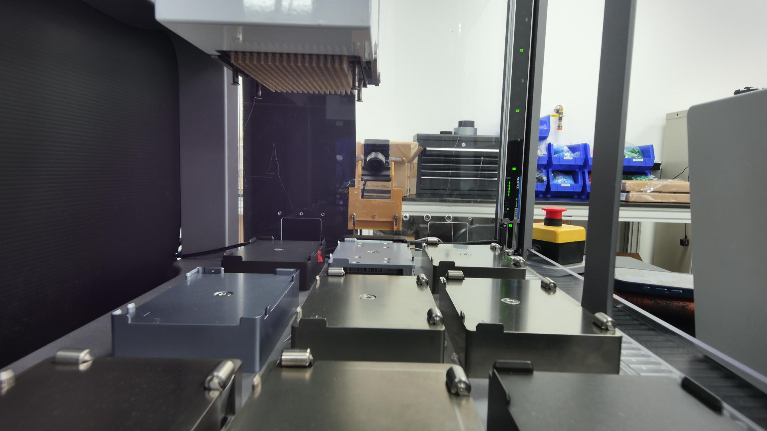
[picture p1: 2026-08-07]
config/vision_reference/deck_reference.png

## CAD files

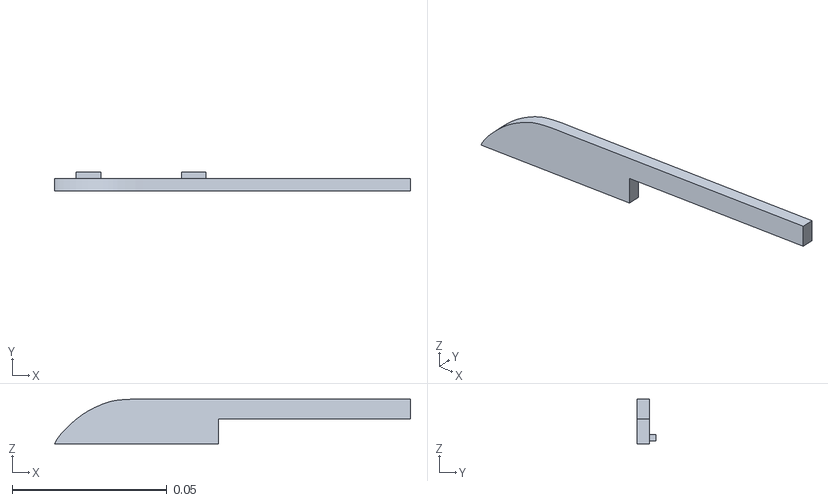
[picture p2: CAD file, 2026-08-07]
pybravo/model/pybravo_urdf/assets/fingerleft.stl
0.115 x 0.006 x 0.0145

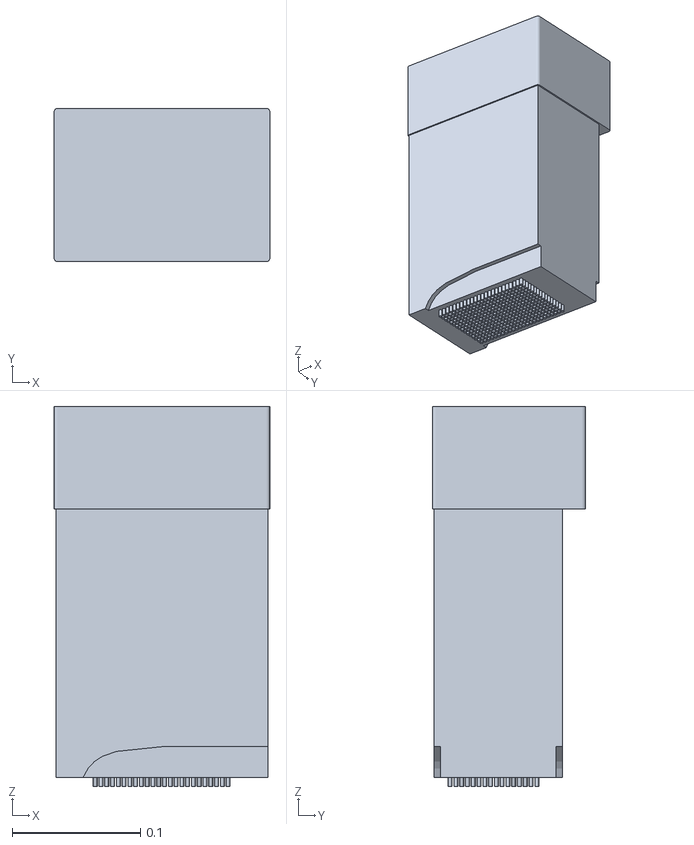
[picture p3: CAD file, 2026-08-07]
pybravo/model/pybravo_urdf/assets/384_head_v2.stl
0.168 x 0.119 x 0.296

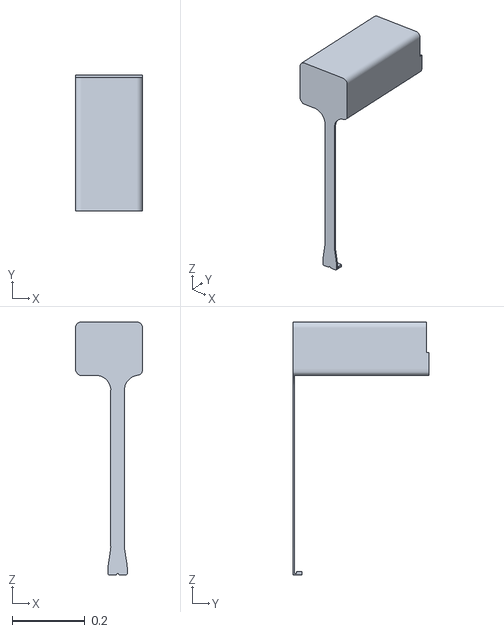
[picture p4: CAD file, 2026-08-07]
pybravo/model/pybravo_urdf/assets/xgantry.stl
0.184 x 0.375 x 0.695

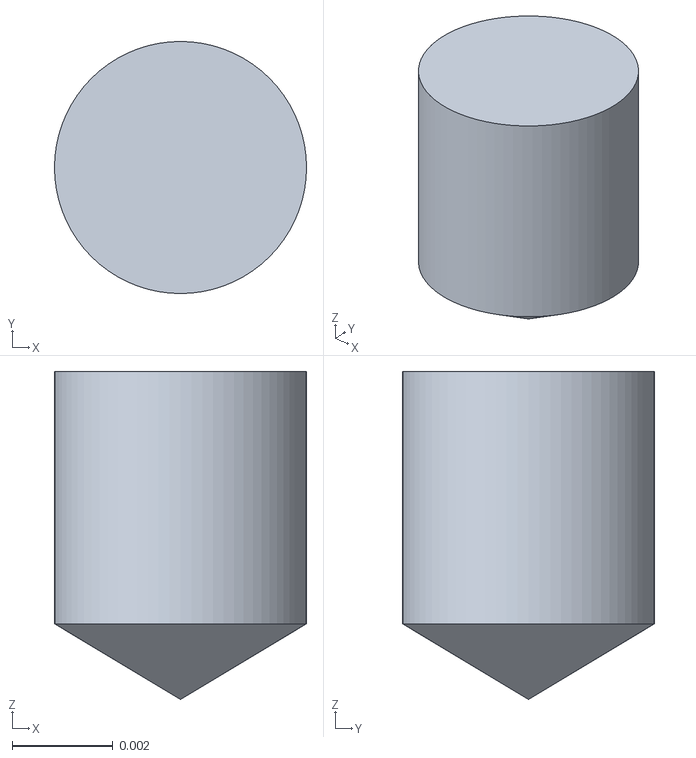
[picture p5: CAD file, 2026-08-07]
pybravo/model/pybravo_urdf/assets/part_3.stl
0.005 x 0.005 x 0.00651

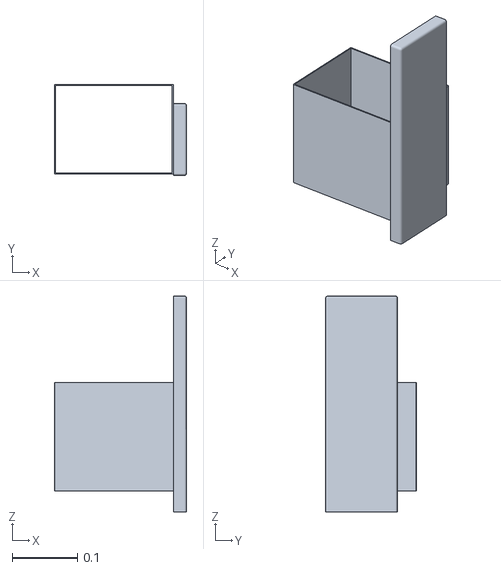
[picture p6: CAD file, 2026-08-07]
pybravo/model/pybravo_urdf/assets/ygantry.stl
0.202 x 0.139 x 0.33

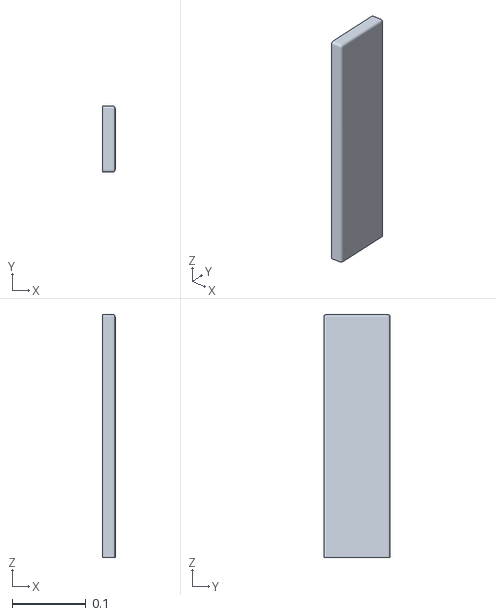
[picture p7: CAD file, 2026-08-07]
pybravo/model/pybravo_urdf/assets/gripperzaxis.stl
0.017 x 0.09 x 0.33

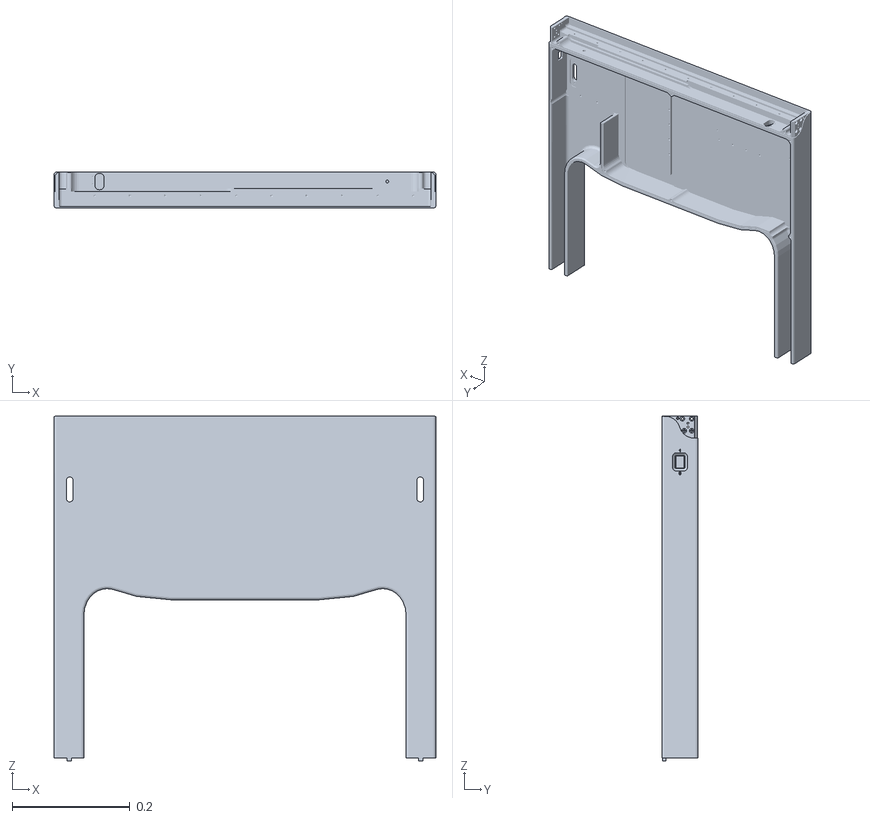
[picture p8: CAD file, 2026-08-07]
pybravo/model/pybravo_urdf/assets/part_5.stl
0.648 x 0.0616 x 0.584

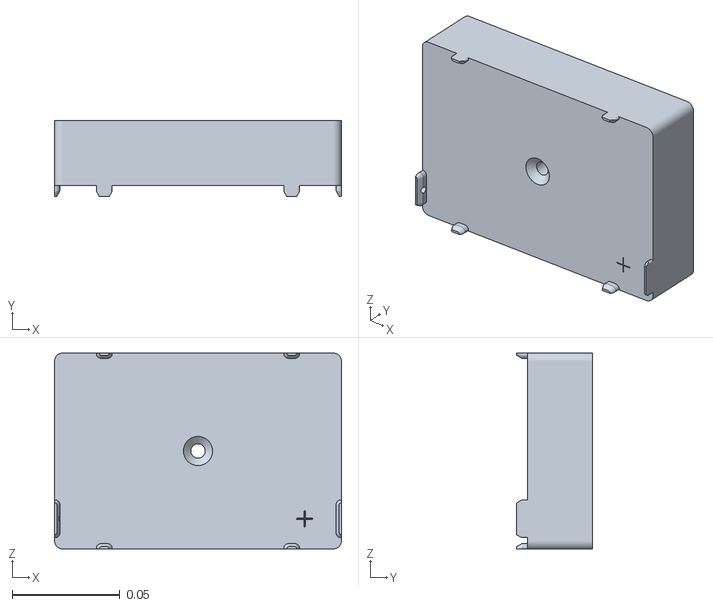
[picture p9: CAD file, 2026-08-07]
pybravo/model/pybravo_urdf/assets/hw1_300_001.stl
0.133 x 0.0351 x 0.0909

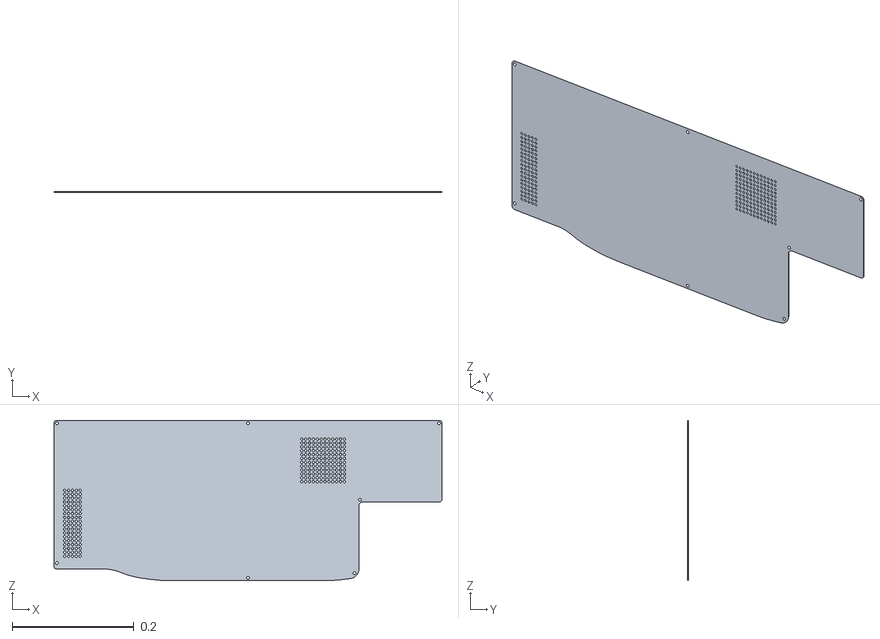
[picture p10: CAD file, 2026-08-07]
pybravo/model/pybravo_urdf/assets/part_6.stl
0.637 x 0.00102 x 0.263

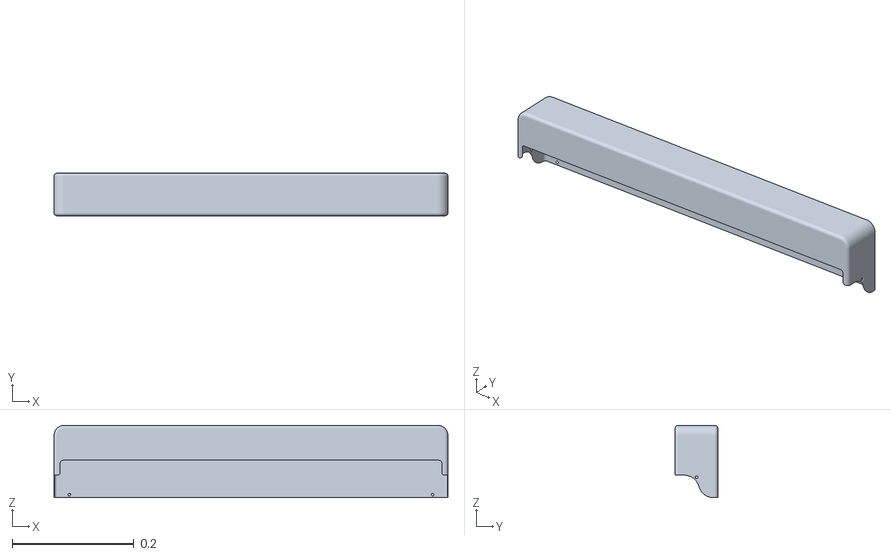
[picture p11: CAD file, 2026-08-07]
pybravo/model/pybravo_urdf/assets/part_1.stl
0.648 x 0.0702 x 0.119

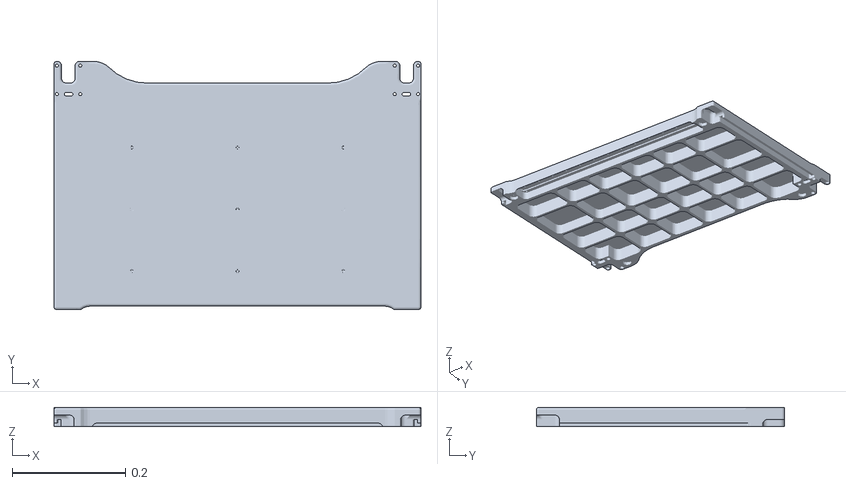
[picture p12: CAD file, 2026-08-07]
pybravo/model/pybravo_urdf/assets/part_4.stl
0.648 x 0.438 x 0.034

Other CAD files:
pybravo/model/pybravo_urdf/assets/fingerright.stl
pybravo/model/pybravo_urdf/assets/part_2.stl
pybravo/model/pybravo_urdf/assets/384_head.stl

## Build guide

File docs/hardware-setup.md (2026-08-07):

# Hardware setup

How to identify your Bravo, put it on the network, describe it in a profile,
teach its deck locations, and attach optional accessories. Work through this
page once per instrument; after that the profile carries the configuration.

> [!WARNING]
> Everything below results in a machine that moves. An incorrect
> `controller_type`, a wrong axis scale, or a mistaught deck location will
> drive the head into the deck. Read [safety.md](safety.md) first, keep a hand
> on the emergency stop, and verify each change in simulation before running it
> on hardware.

---

## 1. Identify your instrument

pyBravo supports several Bravo generations. Each is selected by the
`controller_type` field in the profile's `connection` section.

| Instrument generation | `controller_type` | Connection | Notes |
|---|---|---|---|
| Darwin-generation Bravo | `darwin_native` | TCP, port 7613 | Ethernet only |
| Agile 7612 Bravo | `agile_7612` | TCP, port 7612 | Ethernet only |
| Bravo SRT | `agile_srt` | TCP, port 7612 | Ethernet only; four axes, no gripper |
| Legacy Agile Bravo | `agile` | Serial, or TCP port 10000 | RS-232 at 115200 8-N-1 with RTS/CTS |
| No hardware | `simulation` | — | Default; runs entirely in software |

### Telling them apart

If you do not know which generation you have, the TCP port the instrument
listens on is the most reliable signal. From the host machine, try each port in
turn:

```bash
nc -z -w2 192.168.1.50 7613   # Darwin
nc -z -w2 192.168.1.50 7612   # Agile 7612 or Bravo SRT
nc -z -w2 192.168.1.50 10000  # legacy Agile
```

Additional distinguishing details, all of which the driver relies on:

- **Darwin-generation** instruments answer the UDP discovery broadcast with a
  reply that identifies itself as `DARWIN`, and serve the Gemini protocol on
  TCP 7613.
- **Agile 7612** covers the Bravo 16050-02 (firmware 5.4.6) and Bravo 16060-02
  (firmware 5.4.7). It uses the same command family as the legacy Agile but a
  different frame layout, checksum, and controller identity value, so it is not
  interchangeable with `agile`.
- **Bravo SRT** (firmware 5.4.3) speaks the same wire protocol as the Agile
  7612 on the same port, but has no gripper: only the X, Y, Z, and W axes
  exist. Use `agile_srt`, not `agile_7612`, or homing will attempt axes the
  machine does not have.
- **Legacy Agile** instruments are the only ones that support a serial
  connection. Over Ethernet they listen on TCP 10000.

If a `agile_7612` machine is configured as `agile` (or vice versa) the
connection either fails outright or the controller identity check rejects the
device. That check is deliberate — it is cheaper to fail at connect time than
to send a misinterpreted move command.

---

## 2. Network setup

### Put the host and the instrument on the same subnet

Bravo instruments use a fixed IPv4 address set in the instrument's own
firmware, and pyBravo talks to them over plain TCP. There is no routing or
NAT support, so the host running pyBravo must have an interface on the same
subnet as the instrument.

A typical arrangement is a dedicated instrument network — either a direct
Ethernet cable between the host and the instrument, or both plugged into an
isolated switch:

| Device | Address | Netmask |
|---|---|---|
| Host running pyBravo | 192.168.1.10 | 255.255.255.0 |
| Bravo | 192.168.1.50 | 255.255.255.0 |

Points worth checking:

- The host interface should be configured with a **static** address. A DHCP
  lease that moves the host onto another subnet will silently break discovery
  and connection.
- Local firewalls must allow outbound TCP to the instrument port, and inbound
  UDP on port 7611 if you want broadcast discovery to work.
- Do not put the instrument on a network that reaches the public internet. The
  protocols are unauthenticated and unencrypted.

### Finding the instrument's address

If you already know the address, put it straight into the profile
(`connection.address`) and skip ahead. Otherwise use the discovery endpoint:

```bash
curl -X POST http://localhost:8000/api/discover_devices \
     -H 'Content-Type: application/json' \
     -d '{"adapter": "All interfaces"}'
```

Request fields:

| Field | Default | Purpose |
|---|---|---|
| `adapter` | `"All interfaces"` | Restrict the search to one host interface, given by its IPv4 address. Any other value limits both the broadcast and the sweep to that adapter. |
| `controller_type` | active profile's value | Overrides the profile for this call only. When it resolves to `simulation`, the endpoint returns a single clearly-labelled virtual device and does no network traffic. |

The handler runs three probes concurrently and merges the results by IP
address:

1. **UDP broadcast.** A short discovery datagram is sent to the broadcast
   address of each selected adapter on **UDP port 7611**, and replies are
   collected for about a third of a second. A reply carries the responder's
   service port and a device-type string, which is how Darwin-generation
   instruments are recognised.
2. **TCP subnet sweep.** Candidate addresses are probed in parallel — first
   **port 7613** (Darwin), then **port 10000** with a protocol ping (legacy
   Agile). The candidate list is the host addresses of every selected adapter's
   subnet, plus a built-in default private `/24`. Subnets larger than `/22` are
   skipped rather than swept, and the whole sweep is bounded by a ten-second
   timeout.
3. **Directed probe.** If the active profile already has an address, that
   single address is probed with the same two-port check. This makes a
   known-good machine reappear even when the broadcast is silent and the sweep
   is scoped elsewhere.

The response lists the merged devices and the host interfaces that were
examined:

```json
{
  "devices": [
    {
      "device_id": "SERIAL-OR-IP",
      "device_type": "DARWIN",
      "ip_address": "192.168.1.50",
      "mac_address": "00-00-00-00-00-00",
      "status": "Matched",
      "controller_type": "darwin_native"
    }
  ],
  "adapters": [{"name": "en0", "ip": "192.168.1.10"}]
}
```

`status` is `Matched` when the address equals the one already in the profile,
and `Found` otherwise; matched devices are sorted first.

**Two limitations to be aware of.** The TCP sweep probes ports 7613 and 10000
only, so an **Agile 7612 or Bravo SRT instrument (port 7612) is discovered only
if it answers the UDP broadcast** — otherwise enter its address in the profile
by hand. And the `controller_type` reported by discovery is a best guess from
the probe that succeeded; a device found by broadcast alone is reported as
`agile`. Always confirm the value against
[section 1](#1-identify-your-instrument) before connecting.

To persist a discovered device into the active profile:

```bash
curl -X POST http://localhost:8000/api/select_device \
     -H 'Content-Type: application/json' \
     -d '{"ip_address": "192.168.1.50", "controller_type": "darwin_native"}'
```

This writes `connection.address`, sets `connection.use_ethernet` to true,
optionally sets `connection.controller_type`, and saves the profile to disk.

### Serial connections

Only `controller_type: agile` supports serial. Set `use_ethernet: false` and
put the port name in `serial_port` — `COM3` on Windows, `/dev/ttyUSB0` or
`/dev/tty.usbserial-*` on Linux and macOS. The link is opened at 115200 baud,
8 data bits, no parity, 1 stop bit, with RTS/CTS hardware flow control. The
other controller types reject serial with an explicit error.

---

## 3. Create a profile

A profile is a single YAML file describing one instrument: how to reach it,
what head is installed, how each axis is scaled and limited, where the deck
locations are, and which accessories are attached.

Profiles live in the `profiles/` directory of the repository by default; set
`PYBRAVO_PROFILE_DIR` to move them elsewhere (see
[configuration.md](configuration.md)). Each file is named `<name>.yaml`, and
the file stem is the profile name used by the API. On startup the server loads
the last-used profile, falling back to `simulation.yaml`, and creates a
simulation profile there if nothing exists yet.

The easiest way to start a new instrument is to copy an existing profile:

```bash
curl -X POST http://localhost:8000/api/profile/duplicate \
     -H 'Content-Type: application/json' \
     -d '{"source": "default", "new_name": "my-bravo"}'
```

Then edit `profiles/my-bravo.yaml`, and load it with
`POST /api/profile/load` (`{"name": "my-bravo"}`). Loading requires the robot
to be disconnected.

If you are migrating an instrument that was previously configured under
Windows, `POST /api/profile/import_reg` converts a Windows registry profile
export, and `POST /api/profile/import_dat` converts a legacy `.dat` directory
tree. Both return a `warnings` list; read it, because head-type and tip
identifiers are not mapped automatically and must be set by hand.

### Profile structure

A profile has these top-level sections. Only `connection`, `head`, `axes`, and
`teachpoints` must be correct for safe motion — the rest have workable
defaults.

#### `connection` — how to reach the instrument

| Field | Meaning |
|---|---|
| `controller_type` | Which driver to use. See the table in [section 1](#1-identify-your-instrument). **Getting this wrong is the single most common setup error.** |
| `address` | IPv4 address of the instrument. Required for every non-simulation controller type. |
| `use_ethernet` | `true` for TCP, `false` for serial. Only meaningful for `agile`. |
| `serial_port` | Serial device name, used when `use_ethernet` is `false`. |
| `machine_id` | A stable identifier for this instrument. Liquid classes and pipette techniques are keyed by `machine_id` together with head type and tip, so two instruments with the same `machine_id` share calibration data and two with different ones do not. |

#### `head` — the installed pipette head

| Field | Meaning |
|---|---|
| `head_type` | Enum name of the installed head, for example `HT_96_D_70`, `HT_96_D_200`, `HT_384_D_70`, `HT_8_D_LT`. This drives default teachpoints, tip options, W-axis behaviour, and head geometry used for collision checks. Set it to match the physical head. |
| `check_on_init` | Whether initialization attempts to identify the installed head. Some firmware revisions do not support head detection; set this to `false` there and rely on `head_type`. |
| `default_tip_id` / `default_tip_capacity` | The tip normally used with this head. |
| `teach_tip_id` / `teach_tip_capacity` / `teach_tip_length_mm` | The tip that was on the head when teachpoints were recorded. Z teachpoints are compensated by the difference between the taught tip length and the tip in use, so this must reflect reality or every Z position will be off by the tip-length difference. |

Tip identifiers and lengths come from `config/tips.yaml`; the values above are
normalised against that catalog when the profile is loaded.

#### `gripper` — plate gripper offsets

| Field | Meaning |
|---|---|
| `y_offset` | Y offset applied on top of the location teachpoint when the gripper approaches a plate. This is the field the pick-and-place path actually uses; tune it if plates are picked off-centre in Y. |
| `pad_zg_reference_mm` | Zg at which the gripper bottom sits in the plate-pad plane, measured on your instrument. Default `7.0`. |
| `pad_reference_tip_length_mm` | Length of the tip that was installed when `pad_zg_reference_mm` was measured. Default `26.1` (a 30 µL tip). |
| `grip_current`, `lid_grip_current`, `gripper_position` | Carried for compatibility with imported profiles. The current motion code uses fixed grip currents in the controller rather than these values. |

Whether a gripper exists at all is inferred from the `axes` section: an
instrument is treated as having a gripper when both `G` and `Zg` are present.
Remove them for a gripper-less machine.

##### Teaching the gripper Y offset

> [!WARNING]
> Approach and Move drive the gripper down to the plate's grip plane using the
> location's teachpoint. Verify the teachpoint first — see [safety.md](safety.md).

The gripper does not sit at the same Y as the pipette head, so every pick adds
`gripper.y_offset` to the location's teachpoint Y. It describes how the gripper
is mounted, so there is **one value per machine**, not one per plate.

To teach it, on the Jog/Teach tab under **Gripper Teaching**:

1. Pick the **Location** you are teaching against. The panel shows which
   labware is there, read from the deck; if the location is empty it says so
   and the buttons refuse to run.
2. Press **Approach** to bring the gripper over the plate, stopping the
   entered clearance above the grip plane, then **Move** to go to the plane
   itself.
3. Jog Y until the gripper fingers are centred on the plate.
4. Press **Teach Y Offset**. The offset is saved to the active profile
   immediately, and the log records what changed:

```
Taught gripper Y offset at location 3: Y=7.013, teachpoint Y=9.683,
measured -2.670 mm, head constant -2.250 mm -> stored -0.420 mm (was -0.420)
```

The stored value excludes the per-head constant (−2.25 mm on 384-class heads,
0 otherwise), because pick and place adds that separately. Teaching from the
position the robot already considers correct returns the same number — if
repeated teaching walks the value by 2.25 mm each time, the head constant is
being counted twice.

##### Calibrating the plate-pad reference

> [!WARNING]
> These two fields drive gripper Z motion during pick-and-place. A wrong value
> drives the gripper into the deck. Verify in simulation and watch the first
> real move. See [safety.md](safety.md).

`pad_zg_reference_mm` and `pad_reference_tip_length_mm` are a **pair** and only
mean something together: *with a tip of this length installed, the gripper
bottom touches the plate pad at this Zg.* Pick-and-place then shifts that
reference by the difference between your taught tip and the reference tip, so a
machine taught with longer tips still lands on the same physical plane:

```
Zg reference = pad_zg_reference_mm + (teach tip length − pad_reference_tip_length_mm)
```

With the shipped defaults, a machine whose teach tip is 26.1 mm gets a reference
of 7.0 mm, and one taught with 55.2 mm tips gets 36.1 mm.

To re-measure on your own instrument: install a tip, jog the gripper down until
its bottom is in the plate-pad plane, and record both the Zg reading and the
length of the tip you used. Put those two numbers in the profile together —
changing one without the other silently shifts every pick and place.

Do not set `pad_reference_tip_length_mm` equal to your head's current teach tip
length. That makes the delta zero and removes the compensation entirely, which
looks correct only for machines whose teach tip happens to match the reference.

#### `safety` — guard rails and motion defaults

The fields you are most likely to touch:

| Field | Meaning |
|---|---|
| `z_safe_position` | The Z position treated as "safe" — the retract target used before and between deck moves, and by `POST /api/move_safe_z`. |
| `approach_height` | Default height above a location used when approaching it, including the gripper's descent baseline. |
| `always_move_to_safe_z` | Whether to retract to safe Z before starting a process. |
| `ignore_w_axis` | Skip W (pipettor) homing entirely. Appropriate for pin-tool heads, dangerous otherwise. |
| `prompt_home_w` | Ask the operator to confirm before homing W during initialization. |
| `ignore_plate_sensor` | Continue pick-and-place without the plate sensor. Disables a real safety check; leave `false` unless the sensor is known to be faulty. |
| `run_medium_speed` | Run protocols at the medium speed profile instead of fast. |
| `enable_tips_off_tip_touch` / `tips_off_tip_touch_distance` | Whether tips are bumped sideways against the tip box after ejection, and how far. The distance is expressed in encoder ticks and divided by the X axis's `ticks_per_eng_unit` to get millimetres. |
| `tips_off_z_offset` / `tips_off_w_position` | Default Tips Off geometry. Per-tip-box overrides live in `config/tip_offsets.yaml`. |
| `is_srt` | Marks the machine as a Bravo SRT. Set alongside `controller_type: agile_srt`. |

Remaining `safety` keys exist so that imported profiles round-trip without
losing data; leave them at their defaults unless you know you need them.

#### `vision` — optional depth camera

| Field | Default | Meaning |
|---|---|---|
| `enabled` | `false` | Master switch. While `false`, every `/api/vision/*` endpoint returns 404. |
| `service_url` | `http://127.0.0.1:8101` | Base URL of the vision service the server talks to. |
| `sdk_root` | `external/pyorbbecsdk` | Where the camera SDK is installed. Passed to the vision service launcher. |

See [section 6](#6-optional-hardware) for the full camera setup.

#### `accessories` — non-robot devices

`accessories.devices` is a list of attached devices. Each entry has an `id`,
`type`, `name`, `enabled` flag, a deck `location` (1–9, or 0 for unassigned),
`holds_labware`, and type-specific `connection` and `settings` maps. A legacy
`accessories.barcode_reader` block is also accepted and is kept in sync with
the matching device entry. Supported `type` values are `barcode_reader` and
`teleshake`; see [section 6](#6-optional-hardware).

#### `axes` — per-axis scale, limits, homing, and speeds

One entry per axis (`X`, `Y`, `Z`, `W`, `G`, `Zg`). Any key you omit falls back
to a built-in default, so a profile only needs to state what differs. See
[section 5](#5-axis-calibration).

#### `teachpoints` — deck geometry

Nine entries keyed `'1'` through `'9'`, each with `x`, `y`, and `z` in
millimetres. See [section 4](#4-teach-the-deck-locations).

---

## 4. Teach the deck locations

### The 3×3 deck model

The Bravo deck is modelled as a fixed 3×3 grid of nine locations, numbered left
to right and back to front:

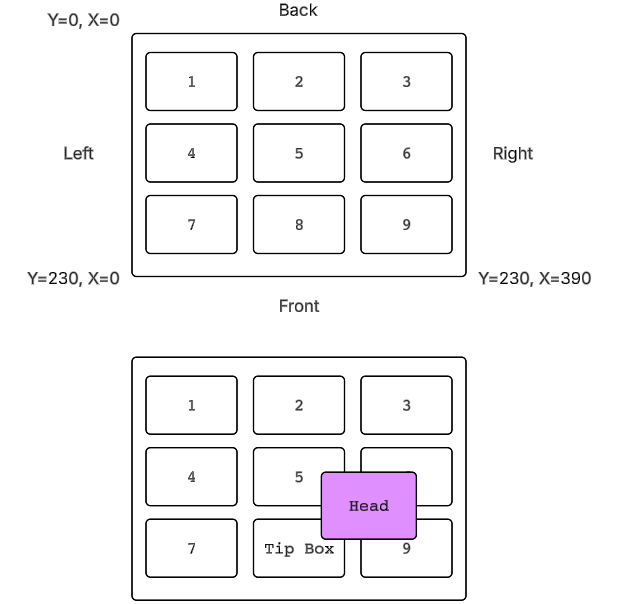
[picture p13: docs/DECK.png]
Deck layout


```
1  2  3      row 0   (Y minimum)
4  5  6      row 1
7  8  9      row 2   (Y maximum)
```

X increases across a row and Y increases from row to row. The nominal spacing
between locations is 186.690 mm in X and 109.093 mm in Y, which is what the
built-in default teachpoints use — location 1 is placed at a head-type-specific
origin and the other eight are derived from it by grid arithmetic.

Those defaults are a starting point, not a calibration. Every real instrument
differs by a millimetre or two, and the default Z is a nominal clearance
height, not a measured one.

### What a teachpoint is

A teachpoint is the X, Y, and Z position of the pipette head, in millimetres,
when it is correctly positioned over a given deck location with the reference
tip installed. Motion to a location — `POST /api/move_to_location`, every
aspirate and dispense, and the gripper's pick-and-place — is computed relative
to that location's teachpoint.

> [!CAUTION]
> A wrong teachpoint is the most direct way to crash this machine. The software
> will drive the head to whatever coordinates the profile contains. Teach with
> the head empty or with tips only, jog in small steps, keep the Z axis high
> until X and Y are confirmed, and read [safety.md](safety.md) before you
> start.

### Teaching a location

1. Connect and initialize the instrument (`POST /api/connect`, then
   `POST /api/initialize`), so all axes are homed and positions are meaningful.
2. Install the tip you intend to use as the teaching reference, and make sure
   `head.teach_tip_id` names it.
3. Jog the head over the target location using `POST /api/jog`:

   ```bash
   curl -X POST http://localhost:8000/api/jog \
        -H 'Content-Type: application/json' \
        -d '{"axis": "X", "step": 1.0, "direction": 1, "speed": "SLOW"}'
   ```

   Jog X and Y first at a safe height, then lower Z in decreasing steps until
   the reference position is reached.
4. Record the current position as the teachpoint:

   ```bash
   curl -X POST http://localhost:8000/api/teachpoint/5/teach_current \
        -H 'Content-Type: application/json' -d '{}'
   ```

   The path segment is the location number, 1–9. The handler reads the live X,
   Y, and Z positions, stores them as that location's teachpoint, updates
   `head.teach_tip_id`, `teach_tip_capacity`, and `teach_tip_length_mm` from
   the tip in use, and saves the profile to disk. An optional body of
   `{"tip_id": "..."}` or `{"tip_capacity": 200.0}` records a different
   reference tip.
5. Verify with `POST /api/move_to_location` at a generous `approach_height`
   before trusting the location in a protocol.

Two related endpoints:

- `GET /api/teachpoint/{location}` returns the stored teachpoint, or `null`
  when the location has none.
- `POST /api/teachpoint/{location}` sets one explicitly from a body of
  `{"x": ..., "y": ..., "z": ...}`. Useful for restoring a known-good value,
  and equally capable of causing a crash if the numbers are wrong.

Teach all nine locations you intend to use. Because the taught Z is
tip-length-compensated, switching to a longer or shorter tip does not require
re-teaching — but it does require the tip definitions in `config/tips.yaml` to
carry correct lengths.

---

## 5. Axis calibration

### Axes and their units

| Axis | Motion | Engineering unit |
|---|---|---|
| `X` | Gantry left–right, across deck columns | mm |
| `Y` | Gantry back–front, across deck rows | mm |
| `Z` | Pipette head vertical | mm |
| `W` | Pipettor plunger / fluid displacement | µL |
| `G` | Gripper open/close | mm |
| `Zg` | Gripper vertical | mm |

### `ticks_per_eng_unit`

This is the encoder scale: how many controller ticks correspond to one
engineering unit on that axis. Every position, velocity, and acceleration the
driver sends is multiplied by it, and every position read back is divided by
it.

Built-in defaults, used when the profile does not override them:

| Axis | Default `ticks_per_eng_unit` |
|---|---|
| `X` | 314.96 |
| `Y` | 314.96 |
| `Z` | 1600.0 |
| `G` | 944.88 |
| `Zg` | 787.40 |
| `W` | 1.0 (placeholder — set this) |

**If `ticks_per_eng_unit` is wrong, every motion on that axis is wrong by the
same ratio.** A value that is half the correct one turns a commanded 10 mm move
into 20 mm of travel; the machine does not know this and will happily drive the
head past the deck. The failure is silent until something collides, which makes
this a value to verify rather than guess: command a known move on a free axis
and measure the actual travel.

Controller-specific behaviour worth knowing:

- `agile_7612` and `agile_srt` load `ticks_per_eng_unit` from the profile for
  every axis at connect time. These are the controllers where the profile value
  matters most.
- The legacy `agile` controller uses its own built-in scales and a W default of
  48.0 ticks per microlitre; it does not read the profile value.
- `darwin_native` works in normalized axis coordinates with its own per-axis
  calibration and does not use `ticks_per_eng_unit`.
- The W axis is scaled in ticks per **microlitre**, not per millimetre, and its
  correct value depends on the installed pipettor. The default written into a
  freshly generated profile is a placeholder; the shipped example profiles use
  448.0. Setting it from the parent-class default instead of the profile is a
  known source of wrong aspirate and dispense volumes.

### Other per-axis fields

| Field | Meaning |
|---|---|
| `min_range` / `max_range` | Software travel limits in engineering units. Motion targets in the gripper and pick-and-place sequences are clamped to this range, and X/Y bounds feed path planning. Widening them past the physical envelope removes a software guard. |
| `homing_offset` | Offset applied between the home sensor and the coordinate origin, so that positions after homing are expressed in deck coordinates. |
| `home_in_positive_direction`, `home_flag_register`, `home_flag_bitmask`, `home_complete_register` | Firmware-level homing parameters. Leave these as imported unless you are working on the driver. |
| `homing_soft_stop_decel`, `min_move_full_accel`, `check_for_alignment` | Motion tuning parameters carried through from the instrument configuration. |
| `<level>_velocity` / `<level>_acceleration` | Speed profiles for each of `fast`, `med`, `slow`, `homing`, and `safe`. Velocities are in engineering units per second, accelerations per second squared. Both keys of a pair must be present for the level to be applied. |

Start from a shipped example profile for your generation rather than an empty
file — the homing register values in particular are not something to derive
from scratch.

---

## 6. Optional hardware

### Depth camera for deck verification

An **Orbbec Femto Bolt** depth camera can be mounted with a fixed view of the
deck and used to check that the physical deck matches the software's model
before a run: which locations are occupied, and whether that agrees with the
configured deck layout.

The camera is driven by a **separate vision service** — a small HTTP service
that owns the camera and exposes preview, calibration, and verification
endpoints. The main server proxies to it and never touches the camera directly.
By default the service listens on **port 8101** at `http://127.0.0.1:8101`.

Setup:

1. **Install the Orbbec SDK separately.** The Python bindings (`pyorbbecsdk`)
   are not a dependency of pyBravo and are not installed by the launcher —
   they must be built or installed for your platform following Orbbec's own
   instructions. Put the result where `vision.sdk_root` points; the default is
   `external/pyorbbecsdk`, which is outside version control. OpenCV
   (`opencv-python`) is also required for frame encoding and previews.
2. **Enable vision in the profile:**

   ```yaml
   vision:
     enabled: true
     service_url: http://127.0.0.1:8101
     sdk_root: external/pyorbbecsdk
   ```

   While `enabled` is `false`, all vision endpoints return 404.
3. **Start the vision service** with `scripts/start_vision_service.sh`
   (`scripts\start_vision_service.bat` on Windows), or directly with
   `python -m pybravo.vision_service`. `POST /api/vision/service/start` will
   launch it for you, but that launcher is implemented for Windows only.
4. **Calibrate.** `POST /api/vision/calibration/run` captures a reference image
   and writes a calibration scaffold. Then define the nine deck regions of
   interest: `POST /api/vision/calibration/roi/start` opens the interactive
   region-marking tool in a new console window (Windows), and the same tool can
   be run directly with
   `python -m pybravo.vision.calibrate_rois <reference-image> [location]`.
   Finally, with an **empty deck**, capture depth baselines using
   `POST /api/vision/calibration/capture_baselines`.
5. **Verify** with `POST /api/vision/verify`, which builds the expected scene
   from the current deck assignments, teachpoints, head type, and tip-box
   occupancy, and returns a per-location report.

Calibration is stored in `config/vision_calibration.yaml` and the reference
image under `config/vision_reference/`. `GET /api/vision/status` reports
whether the service is reachable, whether the SDK imports, and what calibration
exists — start troubleshooting there. If no camera is available the service
falls back to a static reference image, which is useful for development but
tells you nothing about the real deck.

Camera verification is an assistive check, not a safety interlock. It does not
prevent motion.

### Barcode reader

A **Microscan MS-3** fixed-mount scanner can be attached over a serial port and
assigned to a deck location. The reader is an independent device: pyBravo
opens the serial port itself and triggers a read. When a plate at a different
location needs scanning, the plate is picked, placed at the reader's location,
scanned, and returned.

```yaml
accessories:
  devices:
    - id: barcode_reader
      type: barcode_reader
      name: Barcode Reader
      enabled: true
      location: 6
      holds_labware: true
      connection:
        kind: serial
        port: COM5
      settings:
        device_type: ms3
        side: east
```

| Field | Meaning |
|---|---|
| `connection.port` | Serial device name (`COM5`, `/dev/ttyUSB0`, …). |
| `settings.device_type` | Protocol preset. `ms3` is the supported value. |
| `settings.side` | Which side of the plate the scanner reads — `east` or `west`. |
| `location` | Deck location 1–9 where the scanner is mounted. Set this correctly: it determines where plates are moved to be read. |

The `ms3` preset configures the port at 9600 baud, 7 data bits, even parity,
1 stop bit, and handles triggering and no-read responses. Only the port and
device type are user-configurable; the rest of the serial parameters come from
the preset. The driver is created lazily, so selecting a profile does not open
the port — it opens on first use.

### Teleshake orbital shaker

A **Teleshake** orbital shaking station can be attached over serial and placed
at a deck location, where it holds labware like any other position.

```yaml
accessories:
  devices:
    - id: teleshake
      type: teleshake
      name: Teleshake
      enabled: true
      location: 5
      holds_labware: true
      connection:
        kind: serial
        port: COM4
      settings:
        default_rpm: 2000
        default_direction: NE,SW
```

| Field | Meaning |
|---|---|
| `connection.port` | Serial device name. The port is opened at 9600 baud, 8-N-1, no flow control. |
| `settings.default_rpm` | Default shaking speed. Must be between 100 and 2000. |
| `settings.default_direction` | Default orbit pattern. One of `NWSE`, `NESW`, `EW`, `NS`, `NE,SW`, `NW,SE`. |
| `location` | Deck location 1–9 where the shaker sits. |

Control it with `POST /api/accessories/{accessory_id}/teleshake/start` and
`.../stop`, where `accessory_id` is the `id` from the profile. The start
request accepts an RPM and direction to override the defaults. Runtime status
for all configured accessories is available from `GET /api/accessories`.

Note that a shaker occupies deck space and stands taller than a bare deck
position. Teach the location it sits at with the shaker installed.

---

## 7. First run checklist

1. `controller_type`, `address`, and (for serial) `serial_port` are correct.
2. `head.head_type` matches the physical head, and `teach_tip_id` matches the
   tip used for teaching.
3. `axes` scales and ranges came from a profile for your generation, not from
   guesswork.
4. All nine teachpoints have been taught and verified with
   `POST /api/move_to_location` at a generous approach height.
5. Accessory deck locations match where the devices physically are.
6. The protocol has been dry-run in `simulation` mode.
7. You know where the emergency stop is.

---

## See also

- [safety.md](safety.md) — what can go wrong, and how to avoid it
- [installation.md](installation.md) — getting the software running
- [quickstart.md](quickstart.md) — first run in simulation, then first real move
- [configuration.md](configuration.md) — environment variables, config files,
  and profile switching
- [user-guide.md](user-guide.md) — driving the instrument from the web UI
- [api-reference.md](api-reference.md) — full endpoint documentation
- [troubleshooting.md](troubleshooting.md) — connection and motion problems
- [faq.md](faq.md) — common questions

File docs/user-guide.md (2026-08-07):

# User guide

A tour of the pyBravo web interface: the operator dashboard, the editors for
labware, tips and liquid classes, and the normal order of operations for
bringing an instrument from cold to working.

This guide assumes the server is already running and reachable. If it is not,
start with [installation](installation.md) and [quickstart](quickstart.md).

> **This software moves a physical robot.** Most of the controls described
> below command motion the moment they are clicked — there is no separate
> confirmation step. Read [safety](safety.md) before you operate real hardware,
> and keep hands clear of the deck whenever the instrument is connected.

---

## The pages

The server publishes several browser pages from one process:

| Path | Page | Purpose |
|---|---|---|
| `/` | Control panel | Day-to-day operation: connect, home, jog, pipette, move plates |
| `/designer` | Workflow designer | Build, simulate and run node-graph protocols |
| `/labware-editor` | Labware dashboard | Edit labware entries and labware classes |
| `/liquid-class-editor` | Liquid class editor | Edit liquid classes and pipette techniques |
| `/tip-editor` | Tip editor | Edit tip definitions |
| `/vision-calibration` | Vision calibration | Calibrate and verify the optional deck camera |
| `/workflow` | Workflow editor (earlier) | Superseded by `/designer` |

`/workflow` is an earlier, simpler workflow editor that is still served for
backwards compatibility. `/designer` is the actively developed one; use it for
anything new. Everything about it is covered in [workflows](workflows.md).

---

## Order of operations

The instrument has to be brought up in a fixed order. Each step depends on the
one before it.

1. **Pick a profile.** The *Profiles* tab selects which YAML profile is active.
   The profile carries the controller type, network address, head type,
   teachpoints and safety preferences. See [configuration](configuration.md).
2. **Connect.** The `Connect` button in the header opens the transport to the
   instrument. That is all it does — it does **not** initialize the instrument,
   and the robot is not ready for motion until you initialize it separately.
3. **Initialize.** Initialization verifies communication and runs the standard
   startup task sequence for the configured controller. **This causes motion.**
4. **Home.** `Home All` retracts to a safe Z, places the gripper in a safe
   docked state where one is fitted, homes the machine axes, and moves the
   homed axes to their park positions. **This causes motion.** Individual axes
   can be homed from the per-axis `Home` buttons on the *Jog/Teach* and
   *Gripper* tabs.
5. **Describe the deck.** Assign labware to each occupied deck location on the
   *Config* tab. Motion planning, collision checks and the 3D view all depend
   on the software knowing what is physically present.
6. **Work.** Jog, teach, pipette, or run a workflow.

`Abort` in the header signals the task engine to stop the operation currently
running. It is the control to reach for when something looks wrong; for a true
emergency, use the instrument's own emergency stop. `Quit` terminates the
backend server process.

The connection indicator beside the title shows the live transport state, and
the log panel along the bottom of the page records every command and its
result.

---

## The 3D viewport

The left side of the control panel renders a URDF model of the robot — the
digital twin. It mirrors the axis positions streamed from the instrument, and
draws the labware currently assigned to each deck location, tips on the head,
and plates held in the gripper. In simulation mode it is driven by the
simulated controller instead, which is what makes it useful for rehearsing a
layout before any hardware is involved.

The viewport is a display, not a control surface: nothing you do in it moves
the robot.

---

## Control panel tabs

### Jog / Teach

**Axis positions** shows the four machine axes with their live values and a
per-axis `Home` button:

| Axis | Direction | Unit |
|---|---|---|
| X | left / right | mm |
| Y | back / front | mm |
| Z | up / down | mm |
| W | aspirate / dispense (plunger) | µL |

**Jog axes** is a directional pad: `Left −X` / `Right +X`, `Back −Y` /
`Fwd +Y`, `Up −Z` / `Down +Z`, and `Asp +W` / `Dsp −W`. Each group has its own
step-size selector — W in µL, XY in mm, Z in mm — plus a `Speed` selector with
Slow, Medium and Fast. **Every jog button commands immediate motion.** Start
with a small step size, especially near labware.

A `Diagnostics` checkbox reveals a `Z current limit` selector. With it enabled,
Z jogs run in force-limited mode and stop when the selected current is reached.

**Teachpoints** define the reference X, Y and Z coordinates for each of the
nine deck locations. Pick a `Location`, then:

- `Move` drives to the stored teachpoint. **Causes motion.**
- `Approach` drives to the stored teachpoint offset upward by the
  `Approach height` value. **Causes motion.**
- `Teach` writes the robot's current position into that location's teachpoint.
- `Move to Safe Z` retracts Z to the profile's configured safe position.
  **Causes motion.**

The `Tip` selector tells the teaching maths which tip is fitted, since tip
length changes where the head has to sit to reach a given well. Teaching
procedure and tolerances are covered in [hardware setup](hardware-setup.md).

**Multiple axes** offers `Home XYZ` (**causes motion**), `Enable All Motors`
and `Disable All Motors`. Disabling motors removes servo power so axes can be
repositioned by hand — which also means an unsupported axis can fall under its
own weight. Read [safety](safety.md) before disabling motors.

### Gripper

**Gripper axes** shows the two gripper axes with live values and `Home`
buttons: `G` (open/close, mm) and `Zg` (up/down, mm).

**Jog gripper axes** provides `Up −Zg` / `Down +Zg` and `Open −G` / `Close +G`
with their own step selectors. **Causes motion.**

**Gripper actions** are `Open Gripper`, `Close Gripper` and `Dock Gripper`
(opens and stows the gripper). A status lamp reports whether a plate is
detected in the gripper. **All three cause motion.**

**Pick and place** moves labware between two deck locations. Choose
`Location A` and `Location B`, then run `Pick A → Place B` or
`Pick B → Place A`. **These run a full transport sequence** — the gripper
descends, grips, lifts, traverses and sets down. Confirm both locations hold
what you think they hold before running it.

**Gripper teaching** calibrates the gripper against a specific labware type:
choose the `Labware`, set the `Y offset` and `Approach` height, then use
`Teach Y Offset`, `Approach` and `Move`. The latter two **cause motion**.

### Config

**Location configuration** is where the software is told what is on the deck.
Select a `Location` (1–9), a location `Type` (standard platepad or accessory),
and a `Labware` definition, tick `Lidded` and/or `Sealed` as appropriate, then
`Assign Labware`. `Clear Location` removes the assignment.

Accurate deck assignment is not cosmetic. Motion planning, the collision check
that blocks unsafe head moves, tip-box inventory tracking and the 3D view all
read from it. A location that is physically occupied but empty in software is
a collision waiting to happen.

**Deck layout** shows the 3×3 grid with the labware currently assigned to each
position.

**Deck verification** appears when the optional camera is enabled in the
profile. `Verify Deck Setup` compares what the camera sees against what the
software believes is on the deck; `Vision Calibration` opens the calibration
page.

**Accessories** manages hardware attached to a deck location — a barcode
reader or an orbital shaker. Each accessory has a name, ID, type, deck
location, serial port, and a flag for whether it can hold labware. Barcode
readers add a scanner model and a side (east or west); shakers add a default
RPM, a shake direction, an optional temperature-control flag, and `Start` /
`Stop` buttons. **Starting a shaker begins physical agitation.** An optional 3D
model path and Z hint control how the accessory is drawn in the viewport.

### I/O

A read-only diagnostics view of the instrument's discrete signals, refreshed
from the live state stream:

- **Robot status** — robot disable (emergency stop) and motor power fault.
- **Head detection** — whether a head is attached, plus the configured head
  type and a `Refresh` button.
- **Go button** — whether the instrument's go button is pressed.
- **Plate detection** — whether a plate is sensed in the gripper.
- **Motor enable** — per-axis servo power for X, Y, Z and W.

This is the first place to look when an operation refuses to start. See
[troubleshooting](troubleshooting.md).

### Processes

The *Processes* tab runs one high-level operation at a time — the same
operations the workflow designer chains together, executed individually.

Choose a `Location` and confirm the `Labware` assigned there. The **2D
selector** draws the labware's well or tip grid, and is where tip-box pickup
regions are picked directly.

Under **Command parameters**, the `Command` dropdown selects the operation:
Aspirate, Dispense, Mix, Tips On, Tips Off, Stack Plates, Destack Plate, Mount
Plates, Unmount Plate, Delid Plate, Relid Plate, Scan Stack Height, or Read
Barcode. The properties panel below changes to match. `Execute Command` runs
it. **Every command in this list except Read Barcode causes motion.**

Property panels, by command:

- **Aspirate** — volume (µL), pre-aspirate volume, post-aspirate volume,
  liquid class, distance from well bottom (mm), dynamic tip extension (mm/µL),
  tip touch, pipette technique.
- **Dispense** — empty tips, volume (µL), blowout volume, liquid class,
  distance from well bottom (mm), dynamic tip retraction (mm/µL), tip touch,
  pipette technique.
- **Mix** — volume, pre-aspirate volume, blowout volume, liquid class, mix
  cycles, dynamic tip extension, aspirate distance, an optional separate
  dispense distance, tip touch, pipette technique.
- **Stack Plates** / **Mount Plates** — base location and source location,
  each showing the plate currently resolved there.
- **Destack Plate** / **Unmount Plate** — source stack location and
  destination pad.
- **Delid Plate** — plate location and lid destination.
- **Relid Plate** — lid location and plate location.
- **Scan Stack Height** — reports the configured plate, its stacking
  thickness, the measured height, the inferred plate count and the rounded
  stacking height.
- **Read Barcode** — reports the scan result.

Mount and Unmount are the stacking pair that also *locks* the two plates
together, so that a later pick-and-place transports both as a unit. Stack and
Destack move a single plate and leave the pair independent.

At the bottom, the **Head mode** panel shows the current head and its active
mode, with a `Set Head Mode` button that opens the head mode selector.

### Profiles

**Profile management** lists the profiles on disk. `Load` activates one,
`Save Settings` writes the current form back to the active profile, and
`Duplicate…` / `Rename…` manage the files. `Reinitialize` re-runs
initialization against the loaded profile — **this causes motion.** There are
also importers that read settings out of legacy instrument profile exports
(`.reg` files and `.dat` directory trees).

**Connection** selects the `Controller` type and its transport settings:

| Controller | Transport |
|---|---|
| Simulation | none |
| Agile (BioNet Ethernet) | Ethernet |
| Agile 7612 (Ethernet) | Ethernet |
| Bravo SRT (Ethernet) | Ethernet |
| Darwin (Ethernet) | Ethernet |
| Darwin (Serial) | serial port |

Ethernet controllers take an IP address, a machine ID and a device ID, and
offer `Find Available Device` — a discovery scan that lists the devices it can
see with their device ID, type, IP address, MAC address and status, optionally
restricted to one network adapter. Serial controllers take a port name.

**Miscellaneous** holds the safety and behaviour preferences: approach height,
Z safe position, whether to prompt for a W home on first initialization,
medium-speed operation, always moving to safe Z, ignoring the plate sensor
during pick and place, tips-off tip touch, and the deck-verification camera
settings.

**Head information** sets the installed `Head type` and whether to check the
head type on initialize. `Change Head Wizard` walks through a physical head
swap: it warns that the instrument will move to the highest point of location
5, then prompts you to power off, clear all labware, remove the old head,
select the newly installed head, power back on and finish. **The first step
causes motion.**

---

## Head modes and tip selection

A head with many barrels does not have to use all of them. The *head mode* is
the subset of barrels treated as active for tip pickup, tip return and liquid
handling. It is set from the head mode selector (*Processes* tab →
`Set Head Mode`) and read back through the live state.

The selector has three inputs:

- **Subset** — `All barrels`, `Single barrel`, `Full row`, `Full column`, or
  `Rectangle`.
- **Orientation** — which corner the subset is anchored to: front left, front
  right, back left, or back right. `All barrels` always anchors back left.
- **Count** — how many rows or columns (or, for a rectangle, both), shown only
  for the modes that need it.

A preview grid draws the active barrels and marks the anchor corner. Two
shortcuts sit beside it: `Suggest From Labware` proposes a mode based on the
installed head and the labware assigned at a location, and `Reset To All`
returns to the full head.

Head geometry follows the installed head type. The 384-barrel heads and the
384 pin tool are 16 × 24 on a 4.5 mm pitch; the 1536 pin tool is 32 × 48 on a
2.25 mm pitch; the 8- and 16-channel single-column heads are 8 × 1 and 16 × 1;
everything else is 8 × 12 on a 9 mm pitch. Modes that cannot apply to a given
geometry — a row subset on a single-column head, for instance — fall back to
all barrels.

The suggestion logic is straightforward: if the labware's well count matches
the head's channel count, use the full head; a 96-channel head on a 384-well
plate is suggested an 8 × 12 rectangle; an 8-channel head on a 96- or 384-well
plate is suggested a full column; a 16-channel head on a 384-well plate is
suggested a full row.

**Tip selection** is the companion setting: which block of a tip box lines up
with the active subset of the head. It is chosen from the 2D selector on the
*Processes* tab, and is validated against head mode, tip-box geometry and the
box's current inventory. The rules are:

- The selected block must match the active subset's row and column counts.
- For pickup, every well in the block must still hold a tip.
- For return, every well in the block must be empty.
- No tips may remain beyond the block on the side the head approaches from, so
  that partial boxes are consumed from one corner inward rather than leaving
  the head straddling occupied wells.

The selector only offers anchors that satisfy all of these, so an illegal
selection cannot be made by clicking. Full-head modes always anchor at the
back-left corner and need no selection.

Head mode and tip selection persist as instrument state: whatever is set here
applies to subsequent tip and liquid-handling operations until it is changed.

---

## Deck model and labware

The deck is nine locations in a 3 × 3 grid, numbered 1–9. Each location holds
a stack of labware — usually one plate, sometimes a plate with a lid, a plate
mounted on another plate, or a taller stack built by repeated stacking
operations.

Labware definitions come from the catalog managed at `/labware-editor`. The
dashboard has two views, **Labware Entries** and **Labware Classes**. An entry
is edited across several tabs:

- **Plate Properties** — physical dimensions and stacking geometry.
- **Pipette/Well Definition** — the well grid and per-well geometry used to
  compute pipetting positions.
- **Image** — a 2D image asset for the UI.
- **PF400** and **Planar Motor** — gripper and transport parameters for those
  integrations.

Labware classes group compatible entries, which is how lid and plate
compatibility is expressed.

Assigning labware to a location, in either the control panel's *Config* tab or
the designer's deck panel, records the definition plus whether the item is
lidded or sealed, and for tip boxes which tip definition it holds.

---

## Tips, liquid classes and pipette techniques

**Tip definitions** are edited at `/tip-editor`. Each definition has a tip ID,
a display label, a nominal volume in µL, a tip length in mm, an optional 3D
model path, a source field, and the list of heads it is compatible with. Tip
length feeds directly into teaching and into every Z position the software
computes, so it has to be right.

**Liquid classes** are edited at `/liquid-class-editor`. A liquid class is
resolved against a context — machine ID, head type, tip definition and tip
capacity — shown at the top of the editor, so the same class name can carry
different tuning on different instruments or with different tips. Each class
has a name and notes plus three tabs:

- **Aspirate** — plunger velocity, acceleration and post-delay, and the Z-axis
  velocities and accelerations for moving into and out of the liquid.
- **Dispense** — the same set of parameters for the dispense stroke. A
  `Copy values to dispense` / `Copy values to aspirate` button moves settings
  between the two.
- **Equation** — the volume-correction relationship, with a
  `Reset to identity` button.

Changes are committed with `Save changes` or `Save changes as…`.

**Pipette techniques** are managed in the same page. A technique is a reusable
motion pattern layered on top of an aspirate or dispense: a radius in mm, a
number of segments, the Z phase it applies to (entering the liquid, exiting,
or both), a direction, and flags for whether it applies on aspirate, on
dispense, or both. Techniques are referenced by name from any operation that
accepts one, which keeps motion tuning out of individual commands.

Both liquid classes and pipette techniques are validated before a workflow
runs: a reference to a name that does not exist in the current tip and head
context stops the run before any motion, and names the offending nodes.

---

## Live state readout

The control panel subscribes to a WebSocket state stream at `/ws/state`, and
the same snapshot is available as a single request from `GET /api/state`. It
updates roughly 30 times a second in simulation and about five times a second
on hardware, where reads are throttled to avoid competing with motion.

The snapshot carries:

- **Connection** — `connected`, `initialized`, `controller_type`,
  `machine_id`.
- **Motion** — `positions` for every available axis, `motors_enabled` per
  axis, `engine_busy`, and `teachpoints` for all nine locations.
- **Head and tips** — `head_type`, `head_attached`, `head_mode`,
  `tip_selection`, `plate_selection`, plus `tips_on_head`,
  `tips_on_head_mode` and `tips_on_head_selection` describing what is
  physically on the head right now, and `active_tip_id`,
  `active_tip_capacity_ul`, `tip_labware`, `tip_definition_id` and
  `attached_tip_length_mm` describing which tip definition is in play.
- **Deck** — `deck` (labware names per location), `deck_details` (full
  metadata, including whether each item is mounted to the one below it), and
  `tipbox_inventory`.
- **Discretes** — `go_button_pressed`, `plate_in_gripper`, `robot_disabled`.
- **Task** — `task_status` with the running task's current step name, step
  index, step count, status, and error details when a step has failed.
- **Telemetry** — controller-specific diagnostic values.

Full field-by-field documentation is in the [API reference](api-reference.md).

---

## Operator prompts

Some failures pause the run and wait for a decision rather than aborting:

- **Operator action required** — a task step failed. The choices are `Retry`
  (run the step again), `Ignore` (skip it and continue), and `Abort`. Ignoring
  a failed step continues with an instrument in a state the software may no
  longer be tracking correctly; prefer retry or abort unless you understand
  exactly what was skipped.
- **Pickup verification failed** — the gripper may not have acquired a plate.
  The choices are `Retry Pickup`, `Ignore And Continue`, and `Abort`.
- **Process blocked** — the requested move would overlap occupied neighbouring
  deck positions. The dialog reports the command, the head mode, the allowed
  top plane, and a grid of the conflicting positions. This is a pre-motion
  check: nothing has moved. Fix the deck assignment or the head mode and try
  again.

The workflow designer surfaces the same prompts during a run, along with two of
its own for Script nodes — see [workflows](workflows.md).

---

## Where to go next

- [Workflows](workflows.md) — building and running multi-step protocols.
- [Configuration](configuration.md) — profiles, environment variables, files.
- [Hardware setup](hardware-setup.md) — networking, discovery, teaching.
- [API reference](api-reference.md) — driving all of this from code.
- [Architecture](architecture.md) — how the pieces fit together.
- [Troubleshooting](troubleshooting.md) and [FAQ](faq.md).

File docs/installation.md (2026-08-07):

# Installation

How to install pyBravo on macOS, Linux, or Windows, including the optional
LLM extras and the optional camera-based deck verification service. Nothing on
this page requires a robot — the software runs fully in simulation.

---

## Requirements

| Requirement | Notes |
|---|---|
| Python 3.11 or newer | Declared as `requires-python = ">=3.11"` in `pyproject.toml`. 3.11, 3.12, and 3.13 are all supported by the launcher scripts. |
| Git | To clone the repository. |
| An operating system | macOS, Linux, and Windows are all supported. |
| Network access to the instrument | Only needed for real hardware. See [hardware setup](hardware-setup.md). |

The runtime dependencies (FastAPI, uvicorn, pydantic, PyYAML, pyserial,
pymongo, structlog, websockets, python-dotenv, python-multipart) are declared in
`pyproject.toml` and pinned in `uv.lock`. You do not install them by hand.

No database is required. pyBravo can use MongoDB to share a labware catalog
across machines, but a single-machine install works with no database at all —
see the note in [Verifying the install](#verifying-the-install).

---

## Option 1 — install with uv (recommended)

[uv](https://docs.astral.sh/uv/) is a Python package and project manager. It
does three jobs here that otherwise fall to you:

- It downloads and manages a suitable Python interpreter, so you do not need a
  system Python 3.11+ at all.
- It creates and maintains the project virtualenv in `.venv/`.
- It installs the exact dependency versions recorded in `uv.lock`, so everyone
  gets the same environment.

The launcher scripts detect uv automatically. If it is on your `PATH`, they use
it; if it is not, they fall back to other interpreters (see
[How the launcher picks an interpreter](#how-the-launcher-picks-an-interpreter)).

### 1. Install uv

On macOS or Linux:

```bash
curl -LsSf https://astral.sh/uv/install.sh | sh
```

On Windows, follow the installation instructions at
<https://docs.astral.sh/uv/getting-started/installation/>. uv is also available
from Homebrew, `pipx`, and most package managers.

### 2. Clone the repository

```bash
git clone https://github.com/kelsorj/pyBravo.git
```

### 3. Start the server

```bash
cd pyBravo && ./scripts/start_pybravo.sh
```

On Windows, run `scripts\start_pybravo.bat` instead. It performs the same
interpreter search as the shell launcher; see
[Windows specifics](#windows-specifics) for the details that differ.

The first run takes a minute or two while uv fetches an interpreter and builds
the environment. Subsequent runs are fast. The launcher prints the interpreter
it chose, for example:

```
Starting pybravo.web.server with: uv run --frozen python -B -m pybravo.web.server
```

Then open <http://localhost:8000>.

### How the launcher picks an interpreter

`scripts/start_pybravo.sh` and `scripts/start_vision_service.sh` both delegate
to `scripts/_pybravo_launch.sh`, which tries these in order and uses the first
one that works:

1. `$PYBRAVO_PYTHON` — an explicit override. Point it at any interpreter you
   already have, including a conda environment.
2. `uv` — runs `uv run --frozen`, which re-syncs `.venv/` against `uv.lock` on
   every launch. A `git pull` that adds a dependency therefore cannot leave you
   with a stale environment.
3. `./.venv/bin/python` — a virtualenv already present in the repository.
4. `python3.13`, `python3.12`, or `python3.11` on `PATH`.

If none of those is available, the launcher exits with instructions rather than
failing obscurely.

Both launchers pass `-B` to Python so no `.pyc` files are written. This matters
if you are editing controller code — stale bytecode cannot survive a change.

Because the uv path uses `--frozen`, optional extras are pruned unless you ask
for them. Use `PYBRAVO_EXTRAS` to add them:

```bash
PYBRAVO_EXTRAS=llm ./scripts/start_pybravo.sh
```

`PYBRAVO_EXTRAS` accepts a space-separated list, so `PYBRAVO_EXTRAS="llm dev"`
works too.

---

## Option 2 — install with pip and a virtualenv

Use this if you cannot install uv, or you want the environment somewhere you
control. You need a system Python 3.11 or newer.

### macOS and Linux

```bash
git clone https://github.com/kelsorj/pyBravo.git
```

```bash
cd pyBravo && python3.12 -m venv .venv
```

```bash
.venv/bin/pip install -e .
```

```bash
./scripts/start_pybravo.sh
```

The launcher finds `./.venv/bin/python` on its own, so you do not need to
activate the virtualenv first.

### Windows

```bat
git clone https://github.com/kelsorj/pyBravo.git
```

```bat
cd pyBravo && py -3.12 -m venv .venv
```

```bat
.venv\Scripts\activate
```

```bat
pip install -e .
```

```bat
scripts\start_pybravo.bat
```

> **Note on pinning.** `pip install -e .` resolves dependencies fresh against
> PyPI using the version floors in `pyproject.toml`. It does not read
> `uv.lock`. If you need the exact locked versions, use the uv path.

### Running the server directly

Both launchers are thin wrappers. Once an environment exists you can also run:

```bash
python -B -m pybravo.web.server
```

Run this from the repository root. The server resolves the profile directory
relative to the current working directory (`./profiles`), so starting it
elsewhere will create an empty profile directory in the wrong place. Override
it with `PYBRAVO_PROFILE_DIR` if you need to.

---

## Windows specifics

A few things differ on Windows and are worth knowing before you start.

**The launcher searches for an interpreter, same as on macOS and Linux.**
`scripts\start_pybravo.bat` delegates to `scripts\_pybravo_launch.bat`, which
tries, in order:

1. `%PYBRAVO_PYTHON%`, if set.
2. `uv`, which resolves Python 3.11+ and installs from `uv.lock`. This is the
   path you want — it needs nothing else installed.
3. `.venv\Scripts\python.exe`, a virtualenv in the repo.
4. `py -3.13`, `py -3.12`, `py -3.11` via the Windows Python launcher.
5. Plain `python` from `PATH`, **only if it reports 3.11 or newer**.

That last check matters on Windows: the `python` on `PATH` is frequently a 3.9
from the Microsoft Store, and pyBravo needs 3.11. The launcher refuses it with
an explanation and install instructions rather than letting you hit a
`TypeError` raised from inside a class body.

Requesting optional extras under uv uses the same variable as the shell
launcher:

```bat
set PYBRAVO_EXTRAS=llm && scripts\start_pybravo.bat
```

Pointing the launcher at a specific interpreter:

```bat
set PYBRAVO_PYTHON=C:\Users\you\pyBravo\.venv\Scripts\python.exe
```

**Corporate TLS interception.** The `llm` extra includes `pip-system-certs` on
Windows only. On machines behind a re-signing proxy, Python's bundled
certificate store does not trust the corporate CA; `pip-system-certs` makes
`urllib3`/`httpx` use the Windows certificate store instead. It is harmless on
machines without such a proxy.

**Serial ports** are named `COM1`, `COM5`, and so on rather than
`/dev/ttyUSB0`. This applies to the legacy serial controller type and to the
barcode reader configuration in a profile.

**Launching the vision service from the UI** (`POST /api/vision/service/start`)
is implemented for Windows only. On macOS and Linux, start it from the shell —
see [The optional vision service](#the-optional-vision-service).

---

## Optional extras

The project defines two optional dependency groups in `pyproject.toml`.

### `dev` — testing and linting

Adds `pytest`, `pytest-asyncio`, `pytest-cov`, and `ruff`.

With uv (nothing to install ahead of time — uv resolves it per command):

```bash
uv run --extra dev python -m pytest
```

With pip:

```bash
pip install -e ".[dev]"
```

### `llm` — the workflow drafter

Adds `instructor`, `anthropic`, `openai`, `pypdfium2`, and `Pillow` (plus
`pip-system-certs` on Windows). These back the LLM-assisted protocol drafter at
`POST /api/workflow/draft` and the PDF page rendering used by its picker modal.

With uv:

```bash
PYBRAVO_EXTRAS=llm ./scripts/start_pybravo.sh
```

With pip:

```bash
pip install -e ".[llm]"
```

The drafter needs an API key. Copy `.env.example` to `.env` in the repository
root and fill in `ANTHROPIC_API_KEY` or `OPENAI_API_KEY`. The server loads
`.env` at startup; a shell-exported variable takes precedence over the file.
`.env` is gitignored. The same file documents the optional drafter overrides
(`PYBRAVO_DRAFTER_PROVIDER`, `PYBRAVO_DRAFTER_MODEL`, and others) — see
[configuration](configuration.md).

Everything except the drafter works without this extra. If it is not installed,
the drafter endpoints return an error explaining what to install; nothing else
is affected.

---

## The optional vision service

pyBravo can use a depth camera to verify that the physical deck matches what
the software expects before a run. This is optional and disabled by default.

The vision service is a **separate process** listening on port **8101**. The
main server talks to it over HTTP at the URL in the active profile.

### Dependencies you must install yourself

The camera stack is deliberately not part of the base install:

- **The Orbbec SDK Python bindings (`pyorbbecsdk`) are not vendored** with
  pyBravo and are not in `uv.lock`. You install them separately, following
  Orbbec's own build and install instructions for your platform. The default
  location pyBravo expects is `external/pyorbbecsdk` — the `external/`
  directory is gitignored precisely because the SDK lives there and is not part
  of this repository.
- **NumPy** is imported unconditionally by the camera module and is *not* a
  declared project dependency. Install it into the same environment.
- **OpenCV** (`cv2`) is imported optionally and is used for image encoding and
  the region-of-interest overlays. Install it if you want the preview and
  calibration overlays.

### Profile settings

The camera is configured per profile under the `vision:` block. The shipped
defaults are:

```yaml
vision:
  enabled: false
  service_url: http://127.0.0.1:8101
  sdk_root: external/pyorbbecsdk
```

Set `enabled: true` to turn the feature on. Point `sdk_root` at wherever you
actually installed the Orbbec bindings if it is not the default path. These
three fields are editable from the **Profiles** tab in the UI ("Enable deck
verification camera", "Vision service", "Vision SDK root") and via
`PATCH /api/profile`.

While `enabled` is `false`, every `/api/vision/*` endpoint returns
`404 Vision feature is disabled in the active profile`, which is the expected
behavior for a normal install.

### Starting the service

```bash
./scripts/start_vision_service.sh
```

On Windows:

```bat
scripts\start_vision_service.bat
```

Both are thin wrappers around `python -m pybravo.vision_service`, and the shell
version uses the same interpreter-resolution order as the main launcher.

Check it is alive with `GET /api/vision/status` from the main server, or by
requesting the service's own `/status` endpoint on port 8101. If no camera is
attached the service reports `camera_available: false` with the underlying
import or device error in `message`; if `PYBRAVO_VISION_STATIC_IMAGE` points at
an image file, it runs in `static_image` mode for development.

Calibration and day-to-day use are covered in the [user guide](user-guide.md).

---

## Verifying the install

### 1. The server starts and serves the UI

```bash
./scripts/start_pybravo.sh
```

Open <http://localhost:8000>. You should see the PyBravo UI: a header with a
connection indicator, a 3D viewport, and a tabbed side panel. The API's
interactive documentation is at <http://localhost:8000/docs>.

**A MongoDB warning on first run is expected.** The server logs something like:

```
WARNING  pybravo.deck.labware: Falling back to local labware snapshot after Mongo failure: ...
```

This is not an error. The labware catalog can optionally be backed by MongoDB
(configured in `config/labware_catalog.yaml`); when no database is reachable,
pyBravo falls back to a local snapshot and keeps working normally. See
[troubleshooting](troubleshooting.md#the-server-logs-a-mongodb-connection-warning-on-startup)
for the full explanation.

### 2. The tests pass

```bash
uv run --extra dev python -m pytest
```

Or, in an activated virtualenv with the `dev` extra installed:

```bash
python -m pytest
```

Expect roughly **890 passing tests and no failures**. A failing test means
something is wrong with the install or the change you just made — it is not
expected background noise.

- **Some skipped tests.** Skips are normal. Several tests skip when an optional
  fixture or dependency is absent — for example the legacy protocol import
  tests skip without a local protocol fixture, and the vision tests skip when
  NumPy is not installed.

A run that reports only that one failure plus some skips is a healthy install.

### 3. The simulated robot moves

Follow the [quickstart](quickstart.md). It walks through connecting to the
built-in simulation, homing, jogging, and running an aspirate and a dispense —
no hardware required.

---

## Updating

```bash
git pull
```

**If you use uv**, that is the whole update. The launcher runs
`uv run --frozen` on every start, which re-syncs `.venv/` against the
(now updated) `uv.lock` before launching. New dependencies are installed
automatically; removed ones are pruned. If you use optional extras, keep
passing `PYBRAVO_EXTRAS` — `--frozen` prunes extras you do not ask for.

**If you installed with pip**, re-run the install after pulling so any new or
changed dependencies are picked up:

```bash
.venv/bin/pip install -e .
```

Add the extras you use, for example `.venv/bin/pip install -e ".[dev,llm]"`.

After updating, re-run the test suite as described above before you drive real
hardware.

### Your configuration survives an update

Profiles in `profiles/*.yaml` and the catalogs in `config/` are ordinary files
in the working tree. `git pull` will not silently discard local edits, but it
can conflict with them. If you have customised a shipped profile, consider
duplicating it under your own name (Profiles tab → **Duplicate…**, or
`POST /api/profile/duplicate`) so upstream changes to the shipped profiles
never collide with your machine's settings.

---

## Before you connect to real hardware

> **This software drives a physical robot.** It can break labware, damage a
> pipette head, and injure hands. Read [safety](safety.md) before connecting to
> an instrument, and dry-run every new protocol in simulation first.

Installation alone does not touch hardware — nothing moves until you select a
non-simulation controller type and connect. When you are ready, continue with
[hardware setup](hardware-setup.md).

---

## Next steps

- [Quickstart](quickstart.md) — your first fifteen minutes, in simulation.
- [Hardware setup](hardware-setup.md) — networking, finding the instrument,
  profiles, and teachpoints.
- [Safety](safety.md) — read this before the robot moves.
- [Configuration](configuration.md) — profiles, environment variables, catalogs.
- [Troubleshooting](troubleshooting.md) — if any step above did not go as
  described.
- [Architecture](architecture.md) — how the codebase fits together.

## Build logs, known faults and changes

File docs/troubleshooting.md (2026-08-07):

# Troubleshooting

Common symptoms, what usually causes them, and how to fix them. Each entry
follows the same shape: what you see, why it happens, and what to do about it.

> **Some of the failures on this page involve a robot that is already moving,
> or about to.** Where a diagnostic step could cause a crash or an injury, it
> says so. Read [safety](safety.md) before working on a machine that is
> powered and connected.

**Jump to:** [Server startup](#the-server-will-not-start) ·
[The MongoDB warning](#the-server-logs-a-mongodb-connection-warning-on-startup) ·
[Connecting to the robot](#the-server-runs-but-will-not-connect-to-the-robot) ·
[Motion failures](#the-robot-connects-but-will-not-move) ·
[Wrong distances](#an-axis-moves-the-wrong-distance) ·
[Homing and crashes](#homing-fails-or-the-head-crashes-into-the-deck) ·
[Tips](#tips-will-not-pick-up) ·
[The UI](#the-ui-loads-but-positions-and-status-never-update) ·
[Labware](#the-labware-list-is-nearly-empty-or-has-no-tip-boxes) ·
[Tests](#tests-fail) ·
[Debug logging](#turning-on-debug-logging)

---

## How the API reports errors

Knowing the shape of an error response saves time on everything below.

| Cause | HTTP status | Body |
|---|---|---|
| A `RuntimeError` from the driver or task engine | `400` | `{"error": "<message>"}` |
| A `BravoError` (a firmware or protocol-level fault) | `400` | `{"error": "<message>", "error_type": "<ERROR_NAME>"}` |
| Anything unexpected | `500` | `{"error": "Internal server error"}` |

A `500` with that generic body means the real detail is only in the server log.
Go read the terminal the server is running in, or see
[turning on debug logging](#turning-on-debug-logging).

---

## The server will not start

### `SyntaxError`, `TypeError` about `X | None`, or the launcher refuses to run

**Cause.** Python older than 3.11. pyBravo declares
`requires-python = ">=3.11"` and uses syntax that older interpreters cannot
parse.

**Fix.** Check what you actually have:

```bash
python3 --version
```

If it is below 3.11, use one of these:

- Install [uv](https://docs.astral.sh/uv/) and use `./scripts/start_pybravo.sh`.
  uv fetches a suitable interpreter for you.
- Create a virtualenv with a newer Python:
  `python3.12 -m venv .venv && .venv/bin/pip install -e .`
- Point the launcher at an interpreter you already have:
  `PYBRAVO_PYTHON=/path/to/python3.12 ./scripts/start_pybravo.sh`

The shell launcher tries `$PYBRAVO_PYTHON`, then `uv`, then `./.venv/bin/python`,
then `python3.13`/`python3.12`/`python3.11` on `PATH`, and prints installation
advice if none is usable. **The Windows `.bat` launcher does not do this
search** — it runs `%PYBRAVO_PYTHON%` or plain `python`, so on Windows you must
activate the right environment or set `PYBRAVO_PYTHON` yourself.

### `ModuleNotFoundError: No module named 'fastapi'` (or `pydantic`, `yaml`, `uvicorn`, …)

**Cause.** The interpreter that started is not the one with the dependencies
installed. This is almost always a virtualenv that is not active, or a
`PYBRAVO_PYTHON` pointing at the wrong interpreter.

**Fix.** Look at the line the launcher printed —
`Starting pybravo.web.server with: …` — and confirm it names the interpreter
you expect. Then either:

```bash
uv run --frozen python -B -m pybravo.web.server
```

or install into the environment you are actually using:

```bash
.venv/bin/pip install -e .
```

If a *feature* fails rather than startup — a missing `instructor`, `anthropic`,
or `openai` for the workflow drafter — you need the optional `llm` extra. See
[installation](installation.md#optional-extras).

### `Address already in use` / `[Errno 48]` / `[Errno 98]` / `WinError 10048`

**Cause.** Something already holds TCP port 8000. Usually it is a previous
pyBravo server that did not shut down.

**Fix.** Find and stop it. On macOS or Linux:

```bash
lsof -nP -iTCP:8000 -sTCP:LISTEN
```

On Windows:

```bat
netstat -ano | findstr :8000
```

If the previous server is still responsive, the clean way to stop it is the
**Quit** button in the UI, or:

```bash
curl -X POST http://localhost:8000/api/shutdown
```

The port is not configurable from the command line — `run_server()` in
`pybravo/web/server.py` defaults to `8000` and the module entry point does not
take arguments. Free the port rather than trying to move the server. (The
browser UI also hardcodes port 8000 for its state WebSocket, so moving the
server would break live updates anyway.)

### The server starts but nothing is served at `/`

**Cause.** The static UI is mounted only when the `frontend/` directory is
found next to the package. Running the module from an unpacked or partial copy
of the repository can miss it.

**Fix.** Start the server from the repository root, with `frontend/` present.
The API itself still works in this state — check `http://localhost:8000/docs`
to confirm the backend is alive.

---

## The server logs a MongoDB connection warning on startup

**Symptom.** On first run — and every run, if you never configure a database —
the log contains a warning like:

```
WARNING  pybravo.deck.labware: Falling back to local labware snapshot after Mongo failure: <connection details>
```

**This is expected and harmless.** It is the single most common thing that
alarms a new user, and it is not an error.

**Cause.** pyBravo can optionally back its labware catalog with MongoDB so
that several machines in a lab share one definition of every plate and tip box.
You see this warning when a URI *is* configured but the database cannot be
reached. The catalog then falls back to a local snapshot file and the server
carries on; nothing is lost and nothing is broken.

The shipped `config/labware_catalog.yaml` has an empty `mongo.uri`, so a fresh
install reads the local snapshot directly and never emits this warning. If you
are seeing it, something is setting a URI — check that file and the
`PYBRAVO_LABWARE_MONGO_URI` environment variable.

**Fix, if you want the warning gone.** Pick one:

- **Do nothing.** A single-machine install works with no database at all.
- **Clear the URI** in `config/labware_catalog.yaml`:

  ```yaml
  mongo:
    uri: ""
  ```

  Or set the environment variable to empty without editing the file:

  ```bash
  export PYBRAVO_LABWARE_MONGO_URI=
  ```

- **Actually connect a database** by pointing `mongo.uri`, `mongo.database`,
  and `mongo.collection` at your own MongoDB, or setting
  `PYBRAVO_LABWARE_MONGO_URI`, `PYBRAVO_LABWARE_MONGO_DB`, and
  `PYBRAVO_LABWARE_MONGO_COLLECTION`. Environment variables win over the file.

> [!WARNING]
> Do not point this at a MongoDB you use for something else. If the configured
> database is reachable but has no labware collection, the catalog loads as
> empty — successfully, with no warning.

When Mongo *is* reachable you get an informational line instead —
`Loaded N labware definitions from Mongo` — and the local snapshot is refreshed
from it. See [configuration](configuration.md) for the full set of catalog
settings.

---

## The server runs but will not connect to the robot

### `No Bravo IP address is configured. Use 'Find Available Device' and select the device first.`

**Cause.** The active profile has an empty `connection.address` and a
controller type that needs one.

**Fix.** Set the address in the **Profiles** tab → **Connection** → **IP
Address**, or use **Find Available Device** and pick the instrument from the
list. Over the API that is `POST /api/discover_devices` followed by
`POST /api/select_device`, which writes the address into the profile.

### `Could not connect to <address>: …`

Work through these in order.

**Cause 1 — wrong `controller_type` for your machine.** Each generation speaks
a different protocol on a different port, and connecting with the wrong one
fails (or, worse, half-works). Check the profile against the machine you
actually own:

| Instrument generation | `controller_type` | Connection |
|---|---|---|
| Darwin-generation Bravo | `darwin_native` | TCP, port 7613 |
| Agile 7612 Bravo | `agile_7612` | TCP, port 7612 |
| Bravo SRT | `agile_srt` | TCP, port 7612 |
| Legacy Agile Bravo | `agile` | Serial, or TCP port 10000 |
| No hardware | `simulation` | — |

The Agile 7612 and SRT controllers reject serial entirely — they log
`… does not support serial; use Ethernet`. Likewise `darwin_native` is TCP
only.

**Cause 2 — wrong IP address, or the robot is on a different subnet.** Confirm
basic reachability first:

```bash
ping <robot-ip>
```

Then confirm the *port* is open, which is the part that actually matters:

```bash
nc -vz <robot-ip> 7613
```

Substitute the port for your generation from the table above.

**Cause 3 — the discovery sweep does not find your machine.** `POST
/api/discover_devices` (the **Find Available Device** button) runs three probes
in parallel: a UDP broadcast on port 7611, a TCP subnet sweep, and a directed
probe of whatever address is already in the profile. Two limitations catch
people out:

- **The subnet sweep only probes ports 7613 and 10000.** An Agile 7612 or SRT
  machine listening on **7612** will not be found by the sweep. It *will* be
  found by the directed probe if its address is already in the profile — so
  type the IP in by hand once, and discovery will confirm it from then on.
- **The sweep skips subnets larger than `/22`**, and always includes
  `192.168.0.0/24` as a preferred range. On a large corporate network, scanning
  is deliberately not attempted; set the address manually.

### Pressing Home on a single axis does nothing

**Symptom.** The per-axis `Home` button reports success but the axis does not
move. It works right after a power cycle and stops working thereafter.

**Cause.** On Darwin-generation instruments the homing routine skips any axis
that already reports itself initialized — that is deliberate, so reconnecting to
a running instrument does not re-home everything. An explicit operator Home has
to override it.

**Fix.** This is handled as of the current version: `POST /api/home_axis` forces
the routine, so the axis clears its state, searches for the home flag, and homes
regardless of what it reported beforehand. The log confirms it:

```
Homing W axis (operator request; forced)...
Parking W at 0.0 uL after homing (current 5.230 uL)...
```

W is returned to 0 afterwards, matching the state a cold initialize leaves it
in. Other axes are homed but not repositioned, so homing X does not cause an
unrequested lateral move.

### Discovery starts and never finishes

**Symptom.** The log shows the sweep starting and then nothing further:

```
Discover: adapters=1 adapter_ip=all target=192.168.1.50
Scanning 253 IPs for Bravo devices…
```

The UI sits on "Scanning…" and the request never returns.

**Cause.** Some device on the subnet accepts one of the probed ports without
speaking the protocol, and holds the connection. A sweep touches every host on
the LAN, so this is a property of your network, not of the instrument — printers,
KVMs, and management interfaces all do it.

**Fix.** This is bounded as of the current version: a single IP gets
`_PROBE_BUDGET_S` (3 s) and the whole sweep gets `_SCAN_BUDGET_S` (15 s), after
which discovery returns whatever it found and logs how many probes were still
outstanding:

```
Subnet scan hit its 15s budget with 3 of 253 probes still outstanding; returning 1 device(s) found so far.
```

A healthy sweep of a /24 finishes in about 2–3 seconds and logs
`Subnet scan finished in 2.48s -> 1 device(s)`. If you see the budget warning
every time, something on your subnet is stalling probes; set the instrument
address manually rather than relying on the sweep.

Check the server log while discovery runs. It reports what it tried:

```
Discover: adapters=2 adapter_ip=all target=192.168.0.8
Discover: bionet=0 scan=1 directed=hit (842 ms)
```

**Cause 4 — a firewall.** The connection is an outbound TCP connection from the
computer to the instrument, plus a UDP broadcast for discovery. Host firewalls
(macOS application firewall, Windows Defender Firewall, `ufw`/`firewalld`) will
block one or both. Allow the Python interpreter running pyBravo to make
outbound connections and to send UDP broadcasts on port 7611. Corporate
networks frequently block subnet-wide scanning outright, which shows up as
discovery finding nothing while a directed connection works fine.

**Cause 5 — the robot is on a different subnet.** A Bravo commonly ships
configured for a small static network such as `192.168.0.x`. If your computer
is on `10.x` or `172.16.x`, nothing will route. Either put a second network
interface on the robot's subnet, or reconfigure the instrument. This is covered
in [hardware setup](hardware-setup.md).

**Cause 6 — something else is holding the connection.** These controllers
accept a single client. If another copy of pyBravo (or any other client) is
connected, the second connection fails. Make sure only one server is running.

---

## The robot connects but will not move

### `Not connected` on every motion call

**Cause.** The connection dropped between the successful `POST /api/connect`
and the motion call — a cable, a power cycle, or the instrument closing an idle
socket.

**Fix.** Reconnect. If it drops repeatedly, check cabling and look at the
server log with `PYBRAVO_LOG_LEVEL=DEBUG` for the transport error that preceded
it.

### `<axis> axis not initialized; home the axis before issuing a move.` or `Axis is not homed.`

**Cause.** You connected but did not initialize and home. Axis coordinates are
meaningless until the axis has found its reference, and the controller refuses
to move rather than move somewhere arbitrary. You will also see the jog
equivalent: `<axis> axis not initialized; home before jogging.`

**Fix.** Run the three steps in order: **Connect** → **Initialize** →
**Home All**. Over the API, `POST /api/connect`, `POST /api/initialize`,
`POST /api/home`. If only one axis is affected, `POST /api/home_axis` with
`{"axis":"Z"}` homes it alone.

### `Robot safety interlock is active (E-stop). Release the interlock and retry.`

**Cause.** The instrument reports its safety circuit as open. That is an
engaged emergency stop, a broken light curtain, an open door interlock, or a
fault in the disable circuitry (which reports separately as
`Robot disable button circuitry failure.`).

On Darwin machines a mid-motion trip produces a more specific message:

```
Cannot recover: safety interlock still active (SAFETY_STATUS bit 0 set). Clear the light curtain / release E-stop, then retry.
```

**Fix.** Physically clear the condition — release the E-stop, remove whatever
is breaking the light curtain, close the enclosure — and then retry.

> **Do not attempt to bypass a safety interlock in software.** It is the only
> thing standing between a moving head and whatever is in the work envelope.

Confirm the state before retrying:

```bash
curl http://localhost:8000/api/io_status
```

The response has six fields: `robot_disabled`, `head_attached`, `head_type`,
`go_button_pressed`, `plate_in_gripper`, and `motors_enabled` (a per-axis map).
`robot_disabled: true` means the interlock is still open. The same values are
rendered in the **I/O** tab of the UI.

### The task engine is waiting on a prompt

**Cause.** Initialization and several other tasks pause and ask the operator to
confirm something — gripper detection, a plate apparently in the gripper,
whether it is safe to home the W axis. Until you answer, nothing proceeds.

**Fix.** Answer the *Operator Action Required* dialog in the UI. The three
choices map to `POST /api/retry`, `POST /api/ignore`, and `POST /api/abort`:

- **Retry** re-attempts the step.
- **Ignore** skips it and continues. Read the prompt before choosing this —
  ignoring a plate-in-gripper warning means homing the gripper onto a plate.
- **Abort** stops the task.

### `Motor enable timeout`, or an axis is limp

**Cause.** Servo power is off for that axis, either because it was explicitly
disabled or because a fault dropped it.

**Fix.** Check `motors_enabled` in `/api/io_status`, then re-enable:

```bash
curl -X POST http://localhost:8000/api/motor/enable_all
```

> **Disabling a motor removes holding torque.** On a vertical axis that can let
> the assembly drop under its own weight. Support the head before disabling Z,
> and do not disable motors as a way of "resetting" a fault while labware is
> underneath.

---

## An axis moves the wrong distance

**Symptom.** You command 10 mm and get 3 mm, or 100 mm. Positions read back as
plausible numbers, but the physical motion does not match. Nothing errors.

**Cause.** `ticks_per_eng_unit` for that axis is wrong in the profile. This is
the encoder-counts-per-engineering-unit scaling, and every position, velocity,
and acceleration for the axis is multiplied by it. **There is no validation on
this value anywhere** — a wrong number produces silently wrong motion rather
than an error, which is what makes this failure mode dangerous.

The shipped defaults, for reference:

| Axis | Default `ticks_per_eng_unit` | Unit |
|---|---|---|
| X | 314.96 | ticks per mm |
| Y | 314.96 | ticks per mm |
| Z | 1600.0 | ticks per mm |
| G | 944.88 | ticks per mm |
| Zg | 787.4 | ticks per mm |
| W | machine-specific | ticks per **microlitre**, not per mm |

W is the exception worth remembering: it is the aspirate/dispense axis and its
engineering unit is volume, so its scaling is entirely unrelated to the linear
axes and cannot be sanity-checked against them.

**Fix.**

1. **Stop before you experiment.** A scaling error means every commanded move
   overshoots or undershoots, including moves toward the deck. Clear the deck
   and work at slow speed. See [safety](safety.md).
2. Compare the axis block in your profile (`profiles/<name>.yaml`, under
   `axes:`) against the table above and against a known-good profile for the
   same machine generation.
3. Measure. Home the axis, jog a known distance at slow speed, and measure the
   physical travel. The ratio of commanded to actual distance is the ratio your
   `ticks_per_eng_unit` is off by.
4. If you imported the profile from a previous system, re-check the import.
   Windows registry profile exports carry a per-axis "ticks per engineering
   unit" field that maps directly onto this setting, and a partial import can
   leave some axes on library defaults.

Related symptom: **the axis refuses to move at all and reports**

```
Move target 250.0000 mm on X is outside software limits [0.0000, 390.0000].
```

That is the soft-limit check doing its job. Either your target really is out of
range, or `min_range`/`max_range` for the axis are wrong in the profile. Do not
widen the limits to make a move succeed without first understanding why the
target is outside them — the limits are what stop an axis driving into its own
hard stop.

---

## Homing fails or the head crashes into the deck

> **This section describes the failure mode most likely to damage the
> instrument.** Homing moves axes at speed toward reference positions *before*
> the software knows where anything is. Clear the deck, remove plates from the
> gripper, keep hands out, and be ready on the emergency stop. Read
> [safety](safety.md).

### `Axis homing timeout [<axis>]` or `Axis homing retries exceeded [<axis>]`

**Cause.** The axis moved but never reached its home flag within the timeout —
a blocked axis, a failed home sensor, or homing parameters in the profile that
do not match the hardware.

**Fix.**

1. Power down and check the axis moves freely by hand through its full travel.
   Something jammed against a plate or an accessory will produce exactly this.
2. Check the per-axis homing settings in the profile: `home_flag_register`,
   `home_flag_bitmask`, `home_complete_register`, `home_in_positive_direction`,
   `homing_velocity`, `homing_acceleration`, and `homing_offset`. A profile
   copied from a different machine generation is a common source.
3. Home one axis at a time (`POST /api/home_axis`) to isolate which one is
   actually failing, rather than watching a six-axis home fail as a unit.

### `Axis commutation timeout` / `Axis not commutated`

**Cause.** The servo could not establish its commutation reference before
homing. Often a motor power problem, or an axis that cannot move far enough to
commutate because something is in the way.

**Fix.** Clear the obstruction, confirm motor power (`/api/io_status` →
`motors_enabled`), and retry. On Darwin machines a failed gripper commutation
can clamp harder on anything held in the gripper — remove plates from the
gripper before homing.

### `<axis> failed to home`

**Cause.** Homing completed without error but the post-home verification found
the axis not reporting itself as homed.

**Fix.** Retry the single axis. If it repeats, treat it as a hardware or
profile problem as above rather than retrying into it.

### The head drives into the deck, a plate, or a tip box

**Cause.** Almost always one of five things, in rough order of likelihood:

1. **Wrong or missing teachpoints.** Every deck location needs a taught XYZ for
   the labware you actually have there. A teachpoint taught with a short plate
   will crash a tall one.
2. **Wrong labware assigned to a location.** Heights, stack heights, and well
   depths all come from the labware definition. Assigning the wrong plate makes
   every Z calculation wrong. Check the **Config** tab's deck layout against
   the physical deck.
3. **Wrong `ticks_per_eng_unit` on Z** — see
   [an axis moves the wrong distance](#an-axis-moves-the-wrong-distance).
4. **Safe-Z is wrong or disabled.** `safety.z_safe_position` sets the clearance
   height, and `safety.always_move_to_safe_z` controls whether the head
   retracts before travelling. With that disabled, an XY move at working height
   will sweep through everything on the deck.
5. **A profile that does not match the machine.** Axis ranges, head type, and
   controller type all have to be right for the instrument in front of you.

**Fix.** After any crash: stop, power down, inspect the head and the affected
labware for damage before doing anything else. Then re-verify teachpoints one
location at a time, at slow speed, with the approach-height controls in the
**Jog/Teach** tab, before running any protocol. Never re-run the protocol that
crashed to "see if it does it again".

---

## Tips will not pick up

### `Tips On did not encounter the expected tip resistance before reaching the press limit.`

The full message continues: *"The tipbox may be missing, the selected tips may
be absent, or the teachpoint/box height is incorrect. The head was retracted to
safe Z."*

**Cause.** Tip pickup is a force-controlled press. The head descends expecting
to meet resistance from the tips; when it reaches its travel limit without
feeling anything, it concludes there are no tips where it was told to look.
That is one of: no tip box at the location, the box is empty in the selected
columns, the box is the wrong height, or the teachpoint is off.

**Fix.**

1. Confirm a tip box is physically at that location, and that the software
   agrees — **Config** tab → deck layout.
2. Confirm the box is not empty in the region the head is trying to use. The
   **Processes** tab's 2D selector shows tip occupancy.
3. Confirm the labware assigned to the location is the tip box you actually
   have. A mismatched height is enough to cause this.
4. Re-verify the teachpoint for that location.

The dialog offers **Retry**, **Ignore**, and **Abort**. **Ignore** marks the
tips as on and continues — useful when exercising the software without
hardware, and a bad idea on a real run, because everything downstream will
assume tips that are not there.

### `Tips are already on the head` or `<operation> requires a tip box at location <n>`

**Cause.** The software's tip state does not match reality, or the location you
named has no tip box assigned.

**Fix.** Assign the tip box (**Config** tab → **Assign Labware**), or eject the
tips the software thinks are on the head before picking up again.

## Tips will not eject

### `No tips are currently tracked on the head`

**Cause.** The software does not believe tips are on. This commonly happens
after a power cycle or a server restart, which clears tracked tip state while
the physical tips stay on the head.

**Fix.** The dialog's **Ignore** choice proceeds with ejection anyway, which is
the right answer when you can see tips on the head. **Retry** re-checks the
state.

### The tips come off in the wrong place, or catch on the way off

**Cause.** Teachpoint or labware height at the tips-off location, or the
tip-touch settings. `safety.enable_tips_off_tip_touch`,
`safety.tips_off_w_position`, `safety.tips_off_z_offset`, and
`safety.tips_off_tip_touch_distance` in the profile all shape this motion.

**Fix.** Re-verify the teachpoint, then adjust the tips-off settings — see
[configuration](configuration.md).

---

## The UI loads but positions and status never update

**Symptom.** The page renders, buttons work, and API calls succeed — but the
header stays on `Disconnected`, the axis readouts stay at `0.000`, and the 3D
model never moves.

**Cause 1 — you are not connected yet.** The state stream only sends data while
a controller is connected. Before **Connect**, an idle indicator is correct
behavior, not a bug.

**Cause 2 — the WebSocket is blocked.** All live state arrives over
`ws://<host>:8000/ws/state`. REST calls will keep working perfectly with the
WebSocket blocked, which is exactly why this is confusing. Culprits are proxies
that do not forward WebSocket upgrades, browser extensions, and corporate
inspection appliances.

**Cause 3 — you are not on port 8000.** The UI builds its WebSocket URL with
the port hardcoded to `8000`. If you reach the server through a reverse proxy
or a forwarded port on a different number, the page loads over your port but
the WebSocket still tries 8000 and fails.

**Fix.** Open the browser's developer console and look for a failed WebSocket
connection to `/ws/state`. The UI also logs `WebSocket connected` and
`WebSocket disconnected` into its own log panel, and retries every three
seconds — a panel that repeatedly logs disconnects is a blocked socket.

Then:

- Reach the server directly on port 8000 rather than through a proxy.
- If you must proxy, configure it to forward WebSocket upgrade requests, and
  keep the external port at 8000.
- Verify the endpoint independently with any WebSocket client against
  `ws://localhost:8000/ws/state` — you should receive a JSON state document
  several times a second once a controller is connected.

Meanwhile, `GET /api/state` returns the same document over plain HTTP, so you
can keep working while you sort the socket out.

---

## The labware list is nearly empty or has no tip boxes

**Symptom.** The **Labware** dropdown in the Config and Processes tabs offers
only a couple of plates, and no tip box, so you cannot assign one to a
location.

**Cause.** The runtime catalog is built at startup from — in order — MongoDB,
then a local snapshot file, then a small built-in fallback of two plate
definitions. On a fresh clone with no database and no snapshot yet generated,
you get the two-plate fallback.

**Fix.** Any of:

- **Create or edit a labware type** in the labware editor at
  <http://localhost:8000/labware-editor>. Saving writes the snapshot and
  refreshes the runtime catalog immediately. The same thing happens on
  `POST /labware/types` if you would rather do it over the API.
- **Point at a MongoDB** that has your lab's catalog, as described in
  [the MongoDB section](#the-server-logs-a-mongodb-connection-warning-on-startup).
- **Set `PYBRAVO_LABWARE_SNAPSHOT_PATH`** to an existing snapshot file, or the
  `cache.snapshot_path` key in `config/labware_catalog.yaml`.

Confirm what the server currently has:

```bash
curl http://localhost:8000/api/labware
```

---

## The UI renders blank or dead on a machine with no internet access

**Symptom.** On an air-gapped or heavily firewalled lab machine, the page loads
but nothing works — no 3D viewport, buttons do nothing, the log panel stays
empty. The labware editor comes up completely blank.

**Cause.** The browser pages load their JavaScript libraries from public CDNs
at page load: `three.js` from `esm.sh` for the main control page and the 3D
viewport, plus React and Babel from `esm.sh` and `unpkg.com` for the labware
editor. The main page's script is an ES module that imports `three` at the top,
so if that import fails the whole module fails and none of the UI wiring runs.

The interactive API documentation at `/docs` is affected the same way — its
browser assets also come from a CDN.

**Fix.** Either allow the browser (not the server) outbound access to those
hosts, or drive the instrument through the HTTP API instead of the UI. The
backend itself has no such dependency: every endpoint under `/api/` and the
`/ws/state` WebSocket work with no internet access at all, and the raw OpenAPI
schema is served as plain JSON from `/openapi.json`, which needs nothing
external.

For labware specifically, `GET`/`POST`/`DELETE` on `/labware/types` and
`/labware/classes` cover what the labware editor does, and each write refreshes
the runtime catalog. Alternatively, edit the catalog on a machine with internet
access and copy the resulting files across.

---

## Tests fail

Run them with the `dev` extra:

```bash
uv run --extra dev python -m pytest
```

**No failures are expected.** A healthy run reports roughly 890 passes, zero
failures, and some skips. If a test fails, treat it as a real signal rather than
known background noise.

**Skips are normal.** Several tests skip themselves when an optional dependency
or fixture is absent — the legacy protocol import tests skip without a local
protocol fixture, the vision tests skip without NumPy, and some protocol tests
skip without extracted fixture payloads. None of these indicate a problem.

**If many tests fail**, the usual causes are:

- **The wrong environment.** `python -m pytest` uses whichever interpreter is
  first on your `PATH`. Prefer `uv run --extra dev python -m pytest`, which is
  unambiguous.
- **Missing `dev` dependencies.** `pytest-asyncio` in particular is required —
  the suite sets `asyncio_mode = "auto"`, and without the plugin every async
  test errors.
- **Stale bytecode.** Run with `python -B`, or delete `__pycache__` directories,
  after switching branches.
- **A modified profile or config.** Some tests read the shipped files under
  `profiles/` and `config/`. If you have edited them, check `git status` and
  consider testing from a clean checkout.

---

## Turning on debug logging

pyBravo uses Python's standard `logging`, configured centrally in
`pybravo/logging_config.py`. Everything below is controlled by environment
variables, which can also be set in a `.env` file in the repository root (the
server loads it at startup; shell-exported variables take precedence).

### More detail

```bash
PYBRAVO_LOG_LEVEL=DEBUG ./scripts/start_pybravo.sh
```

`DEBUG` adds controller state, position reads, and internal decisions from the
task engine — the right first step for anything involving motion or state that
does not behave as expected.

### Raw protocol frames

```bash
PYBRAVO_PROTOCOL_TRACE=1 ./scripts/start_pybravo.sh
```

This enables `TRACE` (level 5), which hex-dumps protocol frames and raw
transport bytes. Use it when a connection establishes but commands do not do
what you expect. It is verbose; it costs nothing when it is off, because the
formatting is gated behind a level check.

The two combine, and `PYBRAVO_PROTOCOL_TRACE` raises the protocol and transport
loggers independently of the root level, so you can have trace-level wire
output with ordinary `INFO` everywhere else.

### Where the logs go

**By default, to the console** — the terminal running the server. There is no
log file unless you ask for one.

**One rotated file** (10 MB, 3 backups), duplicating console output:

```bash
PYBRAVO_LOG_FILE=/tmp/pybravo.log ./scripts/start_pybravo.sh
```

**Three separate rotated files**, which is what you want when filing a bug:

```bash
PYBRAVO_LOG_DIR=/tmp/pybravo_logs ./scripts/start_pybravo.sh
```

That produces:

| File | Contents |
|---|---|
| `pybravo.log` | Everything, at the configured root level |
| `protocol.log` | `pybravo.protocol.*` and `pybravo.transport.*` only |
| `api.log` | `pybravo.web.*` only — HTTP requests and responses |

`PYBRAVO_LOG_DIR` and `PYBRAVO_LOG_FILE` are mutually exclusive;
`PYBRAVO_LOG_DIR` wins if both are set.

### HTTP request logging

Every HTTP request is logged at `INFO` with method, path, status, and duration:

```
INFO  pybravo.web.http: POST /api/jog -> 200 (12.3ms)
```

High-frequency polling endpoints (`/api/state`, `/api/deck/state`), WebSocket
upgrades, and static assets are skipped so they do not drown out everything
else. If you are trying to confirm the UI is actually reaching the server,
these lines are the fastest check.

### Wire-level counters

For Agile 7612 hardware specifically:

```bash
curl http://localhost:8000/api/diagnostics
```

This returns command counts and the error log from the communications layer. It
is only available for the `agile_7612` controller type.

---

## Still stuck

Collect these before asking for help — they answer most of the first round of
questions:

- The exact error text, including the `error_type` if the response had one.
- `curl http://localhost:8000/api/io_status` and
  `curl http://localhost:8000/api/state`.
- Your active profile (`profiles/<name>.yaml`), with anything sensitive
  removed. The `connection`, `head`, `safety`, and `axes` blocks matter most.
- A server log captured with `PYBRAVO_LOG_LEVEL=DEBUG`, and
  `PYBRAVO_PROTOCOL_TRACE=1` as well if the problem is a connection or a
  command that does not take effect.
- Your instrument generation and the `controller_type` you are using.

Then see the [FAQ](faq.md), the [architecture overview](architecture.md) for
where a given behavior lives in the code, and the
[API reference](api-reference.md) for endpoint semantics.

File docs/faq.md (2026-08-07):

# Frequently asked questions

## About the project

### What is pyBravo?

An open-source control system for Bravo liquid handling robots: a Python driver,
an HTTP and WebSocket API, and a browser UI for running pipetting protocols. It
supports several instrument generations plus a simulator, so you can build and
test protocols without hardware.

### Why does it exist?

A lot of working Bravo instruments are still in labs that can no longer get
software for them. A functioning robot with no usable control software is scrap.
This project keeps those instruments running. See the dedication in the
[README](../README.md).

### Is it affiliated with Agilent?

No. pyBravo is an independent project, not affiliated with, endorsed by, or
supported by Agilent Technologies. Product names are used only to identify the
hardware this software works with. See [NOTICE](../NOTICE).

### What license is it under?

GNU General Public License v3.0 or later. You can use it commercially, modify
it, and distribute it, provided you preserve the license and attribution
notices — and, because GPLv3 is a copyleft license, provided you release the
source of any modified version you distribute under the GPL as well. Running it
in your own lab does not oblige you to publish anything. There is no warranty of
any kind — see [LICENSE](../LICENSE).

### Can I use it for regulated or clinical work?

Not as-is. pyBravo is not a validated instrument control system and is not
certified for clinical, diagnostic, or GxP use. If you operate under a quality
system, validation is your responsibility. Read [Safety](safety.md).

## Getting started

### What do I need to run it?

Python 3.11 or newer. That is all for simulation. See
[Installation](installation.md).

### Can I try it without a robot?

Yes — this is the default. `controller_type: simulation` runs the entire system,
including the UI, the 3D view, and workflow execution, with no hardware
attached. It is also where you should test every new protocol.

### Which instruments are supported?

| Generation | `controller_type` | Connection |
|---|---|---|
| Darwin-generation Bravo | `darwin_native` | TCP 7613 |
| Agile 7612 Bravo | `agile_7612` | TCP 7612 |
| Bravo SRT | `agile_srt` | TCP 7612 |
| Legacy Agile Bravo | `agile` | Serial, or TCP 10000 |
| None | `simulation` | — |

See [Hardware setup](hardware-setup.md).

### How do I find my robot's IP address?

`POST /api/discover_devices` sweeps the network for instruments, or use the
"Find Available Device" control in the UI. Details in
[Hardware setup](hardware-setup.md).

### Why does it warn about MongoDB on startup?

Because MongoDB is optional and you probably do not have it. The labware catalog
can be backed by a shared MongoDB so several machines see the same catalog; when
that is unreachable, the server logs a warning and falls back to a local
snapshot file. Everything works normally. See
[Troubleshooting](troubleshooting.md).

## Using it

### Do I have to home the robot every time?

Yes, after a power cycle. Until an axis is homed, the software does not know
where it is, so positions are meaningless and motion is unsafe. Clear the deck
before homing — see [Safety](safety.md).

### Can I migrate my existing protocols and labware?

Partly. `POST /api/workflow/import` reads legacy XML protocol files, and there
are scripts to import labware definitions and liquid classes from Windows
registry exports (`scripts/import_labware_from_registry.py` and
`scripts/import_liquid_classes_from_registry.py`). Existing instrument profiles
can be imported from `.reg` exports or legacy `.dat` directory trees via
`POST /api/profile/import_reg` and `POST /api/profile/import_dat`.

Treat every import as a draft. Verify teachpoints and simulate before running.

### Can I drive it from my own Python script?

Yes. `pybravo.bravo.Bravo` is the programmatic entry point and is what the web
layer itself uses. Or drive the HTTP API from any language — see the
[API reference](api-reference.md).

### Is there authentication on the API?

No. Anyone who can reach the port can move your robot, and the server binds to
all interfaces by default. Run it on a trusted, isolated network and put it
behind a VPN or authenticating proxy if you need remote access. See
[SECURITY.md](../SECURITY.md).

### What is the LLM drafter, and should I trust it?

An optional feature that drafts a workflow from a text description or a paper
PDF. It requires the `llm` extra and an API key. It produces a **draft**, not a
validated protocol: it can misread volumes, invent steps, or get the deck layout
wrong. Read every generated workflow and simulate it before running it. See
[Workflows](workflows.md).

## Troubleshooting

### It connects but will not move.

Connecting is not initializing. `POST /api/connect` opens the transport;
`POST /api/initialize` prepares the instrument for motion. Then home it. Also
check for an engaged emergency stop or an open safety interlock. See
[Troubleshooting](troubleshooting.md).

### An axis moves the wrong distance.

Almost always `ticks_per_eng_unit` in the profile. If it is wrong by a factor of
ten, a 10 mm move travels 100 mm. Stop and fix the profile before moving again.

### The head crashed into the deck.

Stop and check three things: teachpoints for the location involved, the labware
definition's height, and whether the deck state in software matched reality. All
three are software's model of the world, and nothing senses the physical deck
unless you have the optional camera verification configured.

### Some tests skip when I run the suite.

Normal. Some tests need optional fixtures or hardware and skip when absent.
Nothing should *fail*, though — the suite is green. If you see a failure, it is
worth investigating rather than ignoring.

## Contributing

### How do I help?

See [CONTRIBUTING.md](../CONTRIBUTING.md). Useful contributions that need no
hardware include documentation, tests, UI work, and labware definitions.

### I have an instrument generation you do not support.

That is a valuable contribution. The abstract interface in
`pybravo/controllers/base.py` is the extension point — see
[Architecture](architecture.md). Open an issue before starting so we can help.

### Can I share my profile or labware definitions?

Labware definitions, yes — those describe commercially available consumables and
help everyone. Profiles, generally no: they contain your specific machine's
calibration and teachpoints, which are meaningless on another instrument and
potentially dangerous if someone loads them. Never commit packet captures or
data exported from a real instrument.

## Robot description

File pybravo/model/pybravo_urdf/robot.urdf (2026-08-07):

<?xml version="1.0" ?>
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
<robot name="robot">
  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
  <link name="base_link">
    <inertial>
      <origin xyz="0 0 0" rpy="0 0 0"/>
      <mass value="1e-09"/>
      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
    </inertial>
  </link>
  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
  <link name="hw1_300_001">
    <inertial>
      <origin xyz="0 0 0" rpy="0 0 0"/>
      <mass value="1e-09"/>
      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
    </inertial>
  </link>
  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
  <link name="hw1_300_001_hw1_300_001">
    <inertial>
      <origin xyz="0 0 0" rpy="0 0 0"/>
      <mass value="1e-09"/>
      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
    </inertial>
    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
  </link>
  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
  <joint name="hw1_300_001_hw1_300_001_fixed" type="fixed">
    <origin xyz="-0.18669 0.109093 0.023015" rpy="-1.5708 1.60971e-15 3.14159"/>
    <parent link="hw1_300_001"/>
    <child link="hw1_300_001_hw1_300_001"/>
    <axis xyz="0 0 1"/>
    <limit effort="10" velocity="10"/>
  </joint>
  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
  <joint name="base_link_to_hw1_300_001" type="fixed">
    <origin xyz="0 0 0" rpy="0 -0 0"/>
    <parent link="base_link"/>
    <child link="hw1_300_001"/>
    <axis xyz="0 0 1"/>
    <limit effort="10" velocity="10"/>
  </joint>
  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
  <link name="part_4">
    <inertial>
      <origin xyz="0 0 0" rpy="0 0 0"/>
      <mass value="1e-09"/>
      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
    </inertial>
  </link>
  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
  <link name="xgantry">
    <inertial>
      <origin xyz="0 0 0" rpy="0 0 0"/>
      <mass value="1e-09"/>
      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
    </inertial>
  </link>
  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
  <link name="ygantry">
    <inertial>
      <origin xyz="0 0 0" rpy="0 0 0"/>
      <mass value="1e-09"/>
      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
    </inertial>
  </link>
  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
  <link name="384_head">
    <inertial>
      <origin xyz="0 0 0" rpy="0 0 0"/>
      <mass value="1e-09"/>
      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
    </inertial>
  </link>
  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
  <link name="384_head_384_head">
    <inertial>
      <origin xyz="0 0 0" rpy="0 0 0"/>
      <mass value="1e-09"/>
      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
    </inertial>
    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
  </link>
  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
  <joint name="384_head_384_head_fixed" type="fixed">
    <origin xyz="-1.01371e-05 -0.00832231 -0.08" rpy="0 3.65358e-43 0"/>
    <parent link="384_head"/>
    <child link="384_head_384_head"/>
    <axis xyz="0 0 1"/>
    <limit effort="10" velocity="10"/>
  </joint>
  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
  <joint name="zaxis" type="prismatic">
    <origin xyz="-0.00442215 0.0427703 -0.0615" rpy="-1.5708 5.08796e-29 -1.42074e-14"/>
    <parent link="ygantry"/>
    <child link="384_head"/>
    <axis xyz="0 0 1"/>
    <limit effort="10" velocity="10" lower="-0.105" upper="0"/>
  </joint>
  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
  <link name="gripperzaxis">
    <inertial>
      <origin xyz="0 0 0" rpy="0 0 0"/>
      <mass value="1e-09"/>
      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
    </inertial>
  </link>
  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
  <link name="fingerleft">
    <inertial>
      <origin xyz="0 0 0" rpy="0 0 0"/>
      <mass value="1e-09"/>
      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
    </inertial>
  </link>
  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
  <link name="fingerleft_fingerleft">
    <inertial>
      <origin xyz="0 0 0" rpy="0 0 0"/>
      <mass value="1e-09"/>
      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
    </inertial>
    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
  </link>
  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
  <joint name="fingerleft_fingerleft_fixed" type="fixed">
    <origin xyz="0.0640098 0.000645594 -4.70103e-33" rpy="1.5708 -0 2.07332e-76"/>
    <parent link="fingerleft"/>
    <child link="fingerleft_fingerleft"/>
    <axis xyz="0 0 1"/>
    <limit effort="10" velocity="10"/>
  </joint>
  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
  <joint name="ygripper-left" type="prismatic">
    <origin xyz="-0.0619736 0.051 0.012" rpy="1.5708 2.94796e-38 4.45369e-45"/>
    <parent link="gripperzaxis"/>
    <child link="fingerleft"/>
    <axis xyz="0 0 1"/>
    <limit effort="10" velocity="10" lower="-1.73472e-18" upper="0.021"/>
  </joint>
  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
  <link name="fingerright">
    <inertial>
      <origin xyz="0 0 0" rpy="0 0 0"/>
      <mass value="1e-09"/>
      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
    </inertial>
  </link>
  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
  <link name="fingerright_fingerright">
    <inertial>
      <origin xyz="0 0 0" rpy="0 0 0"/>
      <mass value="1e-09"/>
      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
    </inertial>
    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
  </link>
  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
  <joint name="fingerright_fingerright_fixed" type="fixed">
    <origin xyz="0.0640098 -0.000645578 -0.004" rpy="-1.5708 -0 1.66327e-77"/>
    <parent link="fingerright"/>
    <child link="fingerright_fingerright"/>
    <axis xyz="0 0 1"/>
    <limit effort="10" velocity="10"/>
  </joint>
  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
  <joint name="ygripper-right" type="prismatic">
    <origin xyz="-0.0619736 -0.051 0.012" rpy="-1.5708 -2.58023e-38 -4.6314e-45"/>
    <parent link="gripperzaxis"/>
    <child link="fingerright"/>
    <axis xyz="0 0 1"/>
    <limit effort="10" velocity="10" lower="-0.009" upper="0.012"/>
    <mimic joint="ygripper-left" multiplier="1.0"/>
  </joint>
  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
  <link name="gripperzaxis_gripperzaxis">
    <inertial>
      <origin xyz="0 0 0" rpy="0 0 0"/>
      <mass value="1e-09"/>
      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
    </inertial>
    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
  </link>
  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
  <joint name="gripperzaxis_gripperzaxis_fixed" type="fixed">
    <origin xyz="-0.00847357 -6.10859e-09 -0.165" rpy="3.14159 6.65579e-61 0"/>
    <parent link="gripperzaxis"/>
    <child link="gripperzaxis_gripperzaxis"/>
    <axis xyz="0 0 1"/>
    <limit effort="10" velocity="10"/>
  </joint>
  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
  <joint name="zaxis-gripper" type="prismatic">
    <origin xyz="0.100478 -0.224926 -0.0530846" rpy="1.5708 8.63559e-42 -5.71589e-35"/>
    <parent link="ygantry"/>
    <child link="gripperzaxis"/>
    <axis xyz="0 0 1"/>
    <limit effort="10" velocity="10" lower="0" upper="0.17"/>
  </joint>
  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
  <link name="ygantry_ygantry">
    <inertial>
      <origin xyz="0 0 0" rpy="0 0 0"/>
      <mass value="1e-09"/>
      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
    </inertial>
    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
  </link>
  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
  <joint name="ygantry_ygantry_fixed" type="fixed">
    <origin xyz="0.0905 0.0500739 -0.0530846" rpy="-1.5708 -0 2.13433e-117"/>
    <parent link="ygantry"/>
    <child link="ygantry_ygantry"/>
    <axis xyz="0 0 1"/>
    <limit effort="10" velocity="10"/>
  </joint>
  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
  <joint name="yaxis" type="prismatic">
    <origin xyz="0.211024 0.451844 -0.294946" rpy="-2.47011e-76 -1.5708 0"/>
    <parent link="xgantry"/>
    <child link="ygantry"/>
    <axis xyz="0 0 1"/>
    <limit effort="10" velocity="10" lower="-0.01" upper="0.21"/>
  </joint>
  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
  <link name="xgantry_xgantry">
    <inertial>
      <origin xyz="0 0 0" rpy="0 0 0"/>
      <mass value="1e-09"/>
      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
    </inertial>
    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
  </link>
  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
  <joint name="xgantry_xgantry_fixed" type="fixed">
    <origin xyz="-0.0139762 0.255699 -0.276621" rpy="-1.5708 -1.5708 0"/>
    <parent link="xgantry"/>
    <child link="xgantry_xgantry"/>
    <axis xyz="0 0 1"/>
    <limit effort="10" velocity="10"/>
  </joint>
  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
  <joint name="xaxis" type="prismatic">
    <origin xyz="0.28829 -0.157773 -0.0235762" rpy="1.5708 -0 1.5708"/>
    <parent link="part_4"/>
    <child link="xgantry"/>
    <axis xyz="0 0 1"/>
    <limit effort="10" velocity="10" lower="-0.176058" upper="0.218942"/>
  </joint>
  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
  <link name="part_4_part_4">
    <inertial>
      <origin xyz="0 0 0" rpy="0 0 0"/>
      <mass value="1e-09"/>
      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
    </inertial>
    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
  </link>
  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
  <joint name="part_4_part_4_fixed" type="fixed">
    <origin xyz="0 0 0" rpy="0 -0 0"/>
    <parent link="part_4"/>
    <child link="part_4_part_4"/>
    <axis xyz="0 0 1"/>
    <limit effort="10" velocity="10"/>
  </joint>
  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
  <joint name="base_link_to_part_4" type="fixed">
    <origin xyz="0 0 0" rpy="0 -0 0"/>
    <parent link="base_link"/>
    <child link="part_4"/>
    <axis xyz="0 0 1"/>
    <limit effort="10" velocity="10"/>
  </joint>
  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
  <link name="hw1_300_001_2">
    <inertial>
      <origin xyz="0 0 0" rpy="0 0 0"/>
      <mass value="1e-09"/>
      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
    </inertial>
  </link>
  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
  <link name="hw1_300_001_2_hw1_300_001_2">
    <inertial>
      <origin xyz="0 0 0" rpy="0 0 0"/>
      <mass value="1e-09"/>
      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
    </inertial>
    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
  </link>
  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
  <joint name="hw1_300_001_2_hw1_300_001_2_fixed" type="fixed">
    <origin xyz="0 0.109093 0.023015" rpy="-1.5708 1.60971e-15 3.14159"/>
    <parent link="hw1_300_001_2"/>
    <child link="hw1_300_001_2_hw1_300_001_2"/>
    <axis xyz="0 0 1"/>
    <limit effort="10" velocity="10"/>
  </joint>
  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
  <joint name="base_link_to_hw1_300_001_2" type="fixed">
    <origin xyz="0 0 0" rpy="0 -0 0"/>
    <parent link="base_link"/>
    <child link="hw1_300_001_2"/>
    <axis xyz="0 0 1"/>
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

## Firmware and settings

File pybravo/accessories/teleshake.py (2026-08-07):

import logging
import time
from dataclasses import dataclass
from typing import Any

try:
    import serial
    import serial.tools.list_ports
except ImportError:
    serial = None

logger = logging.getLogger(__name__)


DIRECTION_VALUES = {
    "NWSE": 0x01,
    "NESW": 0x02,
    "EW": 0x10,
    "NS": 0x20,
    "NE,SW": 0x08,
    "NW,SE": 0x04,
}

COMMANDS = {
    "START": 0x30,
    "STOP": 0x31,
    "SET_SPEED": 0x33,
    "SET_DIRECTION": 0x34,
    "APPLY_SETTINGS": 0x3C,
}


@dataclass
class TeleshakeConfig:
    port: str = "COM4"
    baud_rate: int = 9600
    timeout_s: float = 0.6
    default_rpm: int = 100
    default_direction: str = "NWSE"


class TeleshakeError(Exception):
    """Raised when the Teleshake cannot complete a command."""


class Teleshake:
    """Serial driver for the Teleshake orbital shaking station.

    This driver uses the packet shape validated in the standalone
    ``TeleshakeSimpleControl`` helper. It intentionally does not apply any
    teachpoint offsets; deck geometry remains explicit profile data.
    """

    def __init__(self, config: TeleshakeConfig | None = None, **kwargs: Any) -> None:
        self._config = config or TeleshakeConfig(**kwargs)
        self._serial: Any = None
        self._is_running = False

    @property
    def is_open(self) -> bool:
        return bool(self._serial is not None and self._serial.is_open)

    @property
    def is_running(self) -> bool:
        return self._is_running

    @property
    def port(self) -> str:
        return self._config.port

    def open(self) -> None:
        if self.is_open:
            logger.debug("Teleshake already open on %s", self._config.port)
            return
        if serial is None:
            raise ImportError("pyserial is required for Teleshake support. Install it with: pip install pyserial")

        try:
            self._serial = serial.Serial(
                port=self._config.port,
                baudrate=self._config.baud_rate,
                bytesize=serial.EIGHTBITS,
                parity=serial.PARITY_NONE,
                stopbits=serial.STOPBITS_ONE,
                rtscts=False,
                dsrdtr=False,
                timeout=0.1,
            )
            self._serial.setRTS(True)
            self._serial.setDTR(True)
            self._serial.reset_input_buffer()
            self._serial.reset_output_buffer()
        except Exception as exc:
            raise TeleshakeError(f"Could not open Teleshake on {self._config.port}: {exc}") from exc
        logger.info("Teleshake opened on %s at %d baud", self._config.port, self._config.baud_rate)

    def close(self) -> None:
        if self._serial is not None:
            try:
                if self._is_running:
                    self.stop()
            except Exception:
                logger.debug("Ignoring Teleshake stop failure during close", exc_info=True)
            try:
                self._serial.close()
            except Exception:
                logger.debug("Ignoring Teleshake close failure", exc_info=True)
        self._serial = None
        self._is_running = False
        logger.info("Teleshake closed")

    def start(self, rpm: int | None = None, direction: str | None = None) -> None:
        self.open()
        rpm = int(rpm if rpm is not None else self._config.default_rpm)
        direction = direction or self._config.default_direction
        if not 100 <= rpm <= 2000:
            raise TeleshakeError("RPM must be from 100 to 2000")
        if direction not in DIRECTION_VALUES:
            raise TeleshakeError(f"Unknown Teleshake direction: {direction}")

        speed_bytes = self._speed_to_cycle_time_bytes(rpm)
        sequence = [
            ("speed", self._build_packet(COMMANDS["SET_SPEED"], list(speed_bytes))),
            ("direction", self._build_packet(COMMANDS["SET_DIRECTION"], [0x00, 0x00, DIRECTION_VALUES[direction]])),
            ("apply", self._build_packet(COMMANDS["APPLY_SETTINGS"], [0x00, 0xFF, 0xFF])),
            ("start", self._build_packet(COMMANDS["START"], [0x00, 0x00, 0x00])),
        ]
        for label, packet in sequence:
            self._write_packet(label, packet)
            time.sleep(0.08)
        self._is_running = True
        logger.info("Teleshake running on %s at %d RPM, %s", self._config.port, rpm, direction)

    def stop(self) -> None:
        self.open()
        self._write_packet("stop", self._build_packet(COMMANDS["STOP"], [0x00, 0x00, 0x00]))
        self._is_running = False
        logger.info("Teleshake stopped on %s", self._config.port)

    def _write_packet(self, label: str, packet: bytes) -> bytes:
        if not self._serial or not self._serial.is_open:
            raise TeleshakeError("Teleshake is not open")
        try:
            self._serial.reset_input_buffer()
        except Exception:
            pass
        try:
            self._serial.write(packet)
            self._serial.flush()
            reply = self._read_exact(6, timeout_s=self._config.timeout_s)
        except Exception as exc:
            raise TeleshakeError(f"Teleshake {label} command failed: {exc}") from exc
        if logger.isEnabledFor(logging.DEBUG):
            logger.debug(
                "Teleshake %s TX %s RX %s",
                label,
                self._format_hex(packet),
                self._format_hex(reply) if reply else "timeout",
            )
        return reply

    def _read_exact(self, size: int, timeout_s: float) -> bytes:
        if not self._serial or not self._serial.is_open:
            return b""
        deadline = time.time() + timeout_s
        response = bytearray()
        while len(response) < size and time.time() < deadline:
            chunk = self._serial.read(size - len(response))
            if chunk:
                response.extend(chunk)
            else:
                time.sleep(0.01)
        return bytes(response)

    @staticmethod
    def _build_packet(command: int, data: list[int]) -> bytes:
        payload = [0x61, command & 0xFF] + [byte & 0xFF for byte in data[:3]]
        while len(payload) < 5:
            payload.append(0)
        payload.append(sum(payload[:5]) % 256)
        return bytes(payload)

    @staticmethod
    def _speed_to_cycle_time_bytes(rpm: int) -> tuple[int, int, int]:
        cycle_time_us = int(60_000_000 / rpm)
        return (
            (cycle_time_us >> 16) & 0xFF,
            (cycle_time_us >> 8) & 0xFF,
            cycle_time_us & 0xFF,
        )

    @staticmethod
    def _format_hex(data: bytes) -> str:
        return " ".join(f"{byte:02X}" for byte in data)


def main() -> None:
    """Launch the standalone control panel.

    The GUI lives in a separate module so importing this driver never requires
    tkinter, which is absent from some Python builds. Kept here so the familiar
    ``python -m pybravo.accessories.teleshake`` still opens the panel.
    """
    try:
        from pybravo.accessories.teleshake_gui import main as gui_main
    except ImportError as exc:
        raise SystemExit(
            "The Teleshake control panel needs tkinter, which this Python was "
            f"built without ({exc}).\n"
            "Install a Python with Tk support (on macOS: brew install python-tk), "
            "or drive the shaker through the API instead — the serial driver in "
            "this module does not need tkinter."
        ) from exc

    gui_main()


if __name__ == "__main__":
    main()

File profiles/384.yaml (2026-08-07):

name: '384'
connection:
  use_ethernet: true
  address: 192.168.0.51
  serial_port: ''
  controller_type: darwin_native
  machine_id: 04-91-62-CF-7B-B0
head:
  head_type: HT_384_D_70
  check_on_init: true
  default_tip_capacity: 30.0
  teach_tip_capacity: 30.0
  default_tip_id: st_30ul
  teach_tip_id: st_30ul
  teach_tip_length_mm: 26.1
gripper:
  grip_current: 0.15
  lid_grip_current: 0.1
  y_offset: -0.42
  gripper_position: 5.0
  pad_zg_reference_mm: 7.0
  pad_reference_tip_length_mm: 26.1
safety:
  ignore_plate_sensor: false
  ignore_w_axis: false
  simulation_mode: false
  z_safe_position: 0.0
  approach_height: 10.0
  always_move_to_safe_z: true
  prompt_home_w: true
  run_medium_speed: false
  enable_tips_off_tip_touch: false
  is_srt: false
  tips_off_w_position: -9.3
  tips_off_z_offset: 10.0
  tips_off_tip_touch_distance: 314.96
  head_tolerance: 25
  safe_location: 5
  prevent_bravo_during_robotic_access: true
  tip_press_dwell_time: 0
  plate_sensor_transient_ms: 300
  allow_tos_fluid_handling: false
  enable_tips_on_tip_touch: false
  pin_tool_tip_type: 33 mm
vision:
  enabled: true
  service_url: http://127.0.0.1:8101
  sdk_root: external/pyorbbecsdk
accessories:
  devices: []
  barcode_reader:
    enabled: false
    device_type: ms3
    port: COM5
    side: east
    location: 0
axes:
  X:
    ticks_per_eng_unit: 314.96
    min_range: 0.0
    max_range: 390.0
    homing_offset: 193.04
    home_flag_register: 2320
    home_flag_bitmask: 1
    home_in_positive_direction: 1
    home_complete_register: 350
    homing_soft_stop_decel: 300.0
    min_move_full_accel: 40.0
    check_for_alignment: 1
    fast_velocity: 524.0
    fast_acceleration: 1588.0
    med_velocity: 238.0
    med_acceleration: 1270.0
    slow_velocity: 51.0
    slow_acceleration: 200.0
    homing_velocity: 50.0
    homing_acceleration: 100.0
    safe_velocity: 125.0
    safe_acceleration: 200.0
  Y:
    ticks_per_eng_unit: 314.96
    min_range: 0.5
    max_range: 231.0
    homing_offset: 115.443
    home_flag_register: 2320
    home_flag_bitmask: 2
    home_in_positive_direction: 1
    home_complete_register: 351
    homing_soft_stop_decel: 300.0
    min_move_full_accel: 40.0
    check_for_alignment: 1
    fast_velocity: 524.0
    fast_acceleration: 1588.0
    med_velocity: 238.0
    med_acceleration: 1270.0
    slow_velocity: 51.0
    slow_acceleration: 200.0
    homing_velocity: 50.0
    homing_acceleration: 100.0
    safe_velocity: 125.0
    safe_acceleration: 200.0
  Z:
    ticks_per_eng_unit: 1600.0
    min_range: 0.0
    max_range: 150.0
    homing_offset: 0.0
    home_flag_register: 2320
    home_flag_bitmask: 4
    home_in_positive_direction: 0
    home_complete_register: 352
    homing_soft_stop_decel: 300.0
    min_move_full_accel: 0.0
    check_for_alignment: 1
    fast_velocity: 125.0
    fast_acceleration: 375.0
    med_velocity: 63.0
    med_acceleration: 156.0
    slow_velocity: 10.0
    slow_acceleration: 100.0
    homing_velocity: 10.0
    homing_acceleration: 100.0
    safe_velocity: 125.0
    safe_acceleration: 100.0
  W:
    ticks_per_eng_unit: 1692.0
    min_range: -11.01
    max_range: 72.01
    homing_offset: 0.0
    home_flag_register: 2320
    home_flag_bitmask: 8
    home_in_positive_direction: 0
    home_complete_register: 353
    homing_soft_stop_decel: 300.0
    min_move_full_accel: 0.0
    check_for_alignment: 1
    fast_velocity: 600.0
    fast_acceleration: 600.0
    med_velocity: 100.0
    med_acceleration: 200.0
    slow_velocity: 10.0
    slow_acceleration: 200.0
    homing_velocity: 10.0
    homing_acceleration: 100.0
    safe_velocity: 100.0
    safe_acceleration: 200.0
  G:
    ticks_per_eng_unit: 944.882
    min_range: -4.0
    max_range: 10.0
    homing_offset: 0.0
    home_flag_register: 2320
    home_flag_bitmask: 1
    home_in_positive_direction: 0
    home_complete_register: 350
    homing_soft_stop_decel: 300.0
    min_move_full_accel: 0.0
    check_for_alignment: 0
    fast_velocity: 1000.0
    fast_acceleration: 1500.0
    med_velocity: 500.0
    med_acceleration: 500.0
    slow_velocity: 1.0
    slow_acceleration: 10.0
    homing_velocity: 1.0
    homing_acceleration: 10.0
    safe_velocity: 250.0
    safe_acceleration: 10.0
  Zg:
    ticks_per_eng_unit: 787.402
    min_range: -20.0
    max_range: 105.0
    homing_offset: 0.0
    home_flag_register: 2320
    home_flag_bitmask: 2
    home_in_positive_direction: 0
    home_complete_register: 351
    homing_soft_stop_decel: 300.0
    min_move_full_accel: 0.0
    check_for_alignment: 0
    fast_velocity: 1500.0
    fast_acceleration: 1000.0
    med_velocity: 750.0
    med_acceleration: 200.0
    slow_velocity: 100.0
    slow_acceleration: 50.0
    homing_velocity: 10.0
    homing_acceleration: 500.0
    safe_velocity: 125.0
    safe_acceleration: 50.0
teachpoints:
  '1':
    x: 9.29177737236023
    y: 9.98124990463257
    z: 139.00002539157867
  '2':
    x: 195.98172044754028
    y: 10.184498763084413
    z: 139.00002539157867
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

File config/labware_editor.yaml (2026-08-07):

version: 1
labware_types:
- labware_type_id: lw-3918306f45b8
  name: 1536 Labcyte LP-0400 LDV
  kind: sbs_plate
  vendor: ''
  catalog_number: ''
  description: ''
  base_class: microplate
  wells: 1536
  plate_dimensions_mm:
    length_mm: 127.76
    width_mm: 85.48
    height_mm: 10.5
  plate_properties:
    robot_gripper_offset_mm: 1.0
    empty_check_offset_mm: null
    thickness_mm: 10.48
    stacking_thickness_mm: 9.8
    shim_thickness_mm: null
    can_be_sealed: true
    sealed_thickness_mm: 10.5
    sealed_stacking_thickness_mm: 9.3
    can_have_lid: false
    lidded_thickness_mm: null
    lidded_stacking_thickness_mm: null
    lid_resting_height_mm: null
    lid_departure_height_mm: null
    lower_plate_at_labeler: false
    can_mount: false
    can_be_mounted: false
    max_robot_handling_speed: fast
    filter_tip_pin_tool_length_mm: null
    filter_channel_resting_depth_mm: null
    requires_insert: None
  well_dimensions_mm:
    volume_ul: 5.5
    depth_mm: 5.2
    diameter_mm: 1.7
    offset_x_mm: 3.375
    offset_y_mm: 3.375
    spacing_x_mm: 2.25
    spacing_y_mm: 2.25
    well_geometry: 2
    well_bottom_shape: 2
    tip_source: agilent
    disposable_tip_capacity_ul: 10
    disposable_tip_length_mm: null
  pf400: {}
  planar_motor: {}
  labware_class_ids:
  - 01KD4PKQ8DFP12QWDM29CQWZ8A
  model_3d:
    url: /labware-assets/lw-3918306f45b8/1536_Labcyte_LP-0400_LDV.gltf
    filename: 1536_Labcyte_LP-0400_LDV.gltf
    format: gltf
  tip_definition_id: ''
  supported_tip_ids: []
- labware_type_id: lw-34358f93e2a0
  name: 384 CellVis 1.5H
  kind: sbs_plate
  vendor: ''
  catalog_number: ''
  description: ''
  base_class: microplate
  wells: 384
  plate_dimensions_mm:
    length_mm: 127.76
    width_mm: 85.48
    height_mm: 14.3
  plate_properties:
    robot_gripper_offset_mm: 8
    empty_check_offset_mm: null
    thickness_mm: 14.3
    stacking_thickness_mm: null
    shim_thickness_mm: null
    can_be_sealed: false
    sealed_thickness_mm: null
    sealed_stacking_thickness_mm: null
    can_have_lid: true
    lidded_thickness_mm: 16.4
    lidded_stacking_thickness_mm: 17.7
    lid_resting_height_mm: 9.7
    lid_departure_height_mm: 11
    lower_plate_at_labeler: false
    can_mount: false
    can_be_mounted: false
    max_robot_handling_speed: fast
    filter_tip_pin_tool_length_mm: null
    filter_channel_resting_depth_mm: null
    requires_insert: None
    robot_lid_gripper_offset_mm: 0.5
  well_dimensions_mm: {}
  pf400: {}
  planar_motor: {}
  labware_class_ids:
  - 01KD4PKQ8DFP12QWDM29CQWZ8A
  tip_definition_id: ''
  supported_tip_ids: []
  model_3d: null
- kind: sbs_plate
  name: 384 Labcyte PP0200 PP sq flt
  vendor: Beckman
  catalog_number: 001-14622
  description: Echo(R) Qualified 384-Well Polypropylene Microplate, Clear, Sterile,
    Surface-treated with Amine Coating
  base_class: microplate
  labware_class_ids:
  - 01KD4PKQ8DFP12QWDM29CQWZ8A
  wells: 384
  well_type: ''
  plate_dimensions_mm:
    length_mm: 127.76
    width_mm: 85.48
    height_mm: 14.4
  plate_properties:
    robot_gripper_offset_mm: 7
    empty_check_offset_mm: null
    thickness_mm: 14.4
    stacking_thickness_mm: 13.6
    shim_thickness_mm: 4
    can_be_sealed: true
    sealed_thickness_mm: 0
    sealed_stacking_thickness_mm: 0
    can_have_lid: true
    lidded_thickness_mm: 16.5
    lidded_stacking_thickness_mm: 14.5
    lid_resting_height_mm: 9.5
    lid_departure_height_mm: 8.5
    lower_plate_at_labeler: true
    can_mount: true
    can_be_mounted: true
    max_robot_handling_speed: fast
    filter_tip_pin_tool_length_mm: 0
    filter_channel_resting_depth_mm: 0
    requires_insert: None
    robot_lid_gripper_offset_mm: null
  well_dimensions_mm:
    diameter_mm: 3.5
    depth_mm: 11.4
    volume_ul: 130
    spacing_x_mm: 4.5
    spacing_y_mm: 4.5
    offset_x_mm: 2.25
    offset_y_mm: 2.25
    rows: 16
    cols: 24
    well_geometry: 2
    well_bottom_shape: 2
    tip_source: agilent
    disposable_tip_capacity_ul: 10
    disposable_tip_length_mm: 20
  model_3d:
    url: /labware-assets/01KD4PYY7N4EG0E22P3QP1RHB9/384_Greiner_781091_PS_uclear.gltf
    filename: 384_Greiner_781091_PS_uclear.gltf
    format: gltf
  notes: Seeded from vendor .dat; verify dimensions + map geometry/base class enums.
  source:
    system: legacy
    dat_path: models/labware/384 Greiner 781091 PS uclear/384 Greiner 781091 PS uclear.dat
    folder: 384 Greiner 781091 PS uclear
    image_filename: ''
  legacy_raw:
    3RD_PARTY_TIP_CAPACITY: '60'
    A12_NOTCH: '0'
    A1_NOTCH: '1'
    ACCESS2_IGNORE_PLATE_SENSOR: '0'
    ACCESS2_ROBOT_GRIPPER_OFFSET: '6.00000'
    ACCESS2_ROBOT_LID_GRIPPER_OFFSET: '0.00000'
    BASE_CLASS: '1'
    BC_ERROR_CORRECTION_OFFSET: '0.00000'
    BC_GRIPPER_HOLDING_LIDDED_PLATE_POSITION: '4.00000'
    BC_GRIPPER_HOLDING_LID_POSITION: '3.50000'
    BC_GRIPPER_HOLDING_PLATE_POSITION: '4.00000'
    BC_GRIPPER_HOLDING_STACK_POSITION: '4.50000'
    BC_GRIPPER_OPEN_POSITION: '0.10000'
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

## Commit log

2026-08-07 added configs
    [vision_calibration.yaml]
2026-08-07 added rest of stack
    [384_head.stl, 384_head_v2.stl, fingerleft.stl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]
2026-08-07 Prepare repository for public launch
    The application itself was in good shape (892 tests green); nearly everything
    blocking a new contributor was packaging and repo hygiene.
    Packaging — a fresh clone could not run at all:
    - Restore pyproject.toml. It had never been committed; the dependency list was
    recoverable only from the stale pybravo.egg-info build artifact. Without it
    `uv run --frozen` (what the launcher executes) silently fell through to
    whatever interpreter it found, with no dependencies.
    - Add uv.lock, which `uv run --frozen` hard-requires.
    - Mark scripts/*.sh executable. `./scripts/start_pybravo.sh` straight from the
    README failed with permission denied.
    - Set asyncio_mo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
    [agile_7612.py, axis.py]
2026-08-07 Windows launcher: sync with uv, then run .venv's python by path
    `uv run python -B -m pybravo.web.server` works from PowerShell but not from
    cmd.exe. CI proved it on the same runner, same directory, with .venv already
    built: pwsh resolved .venv\Scripts\python.exe, while the identical command
    inside cmd resolved C:\hostedtoolcache\...\python.exe and died with
    ModuleNotFoundError: No module named 'pybravo'.
    uv runs the child with .venv\Scripts prepended to PATH; under cmd.exe that
    does not take effect, so the child picks up whatever Python is already on PATH.
    Any Windows box with a system Python would hit this, which is exactly the
    audience the .bat exists for.
    Run `uv sync --frozen` and then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
2026-08-07 Windows launcher: capture %~dp0 before shift, not after
    The launcher never reached the repository root. In batch, `shift` renumbers %0
    along with %1..%9, so the `cd /d "%~dp0.."` after the argument-collecting
    shifts resolved against the consumed argument rather than the script. uv then
    ran outside the project.
    That is the actual cause of the ModuleNotFoundError chased over the last few
    commits, and it was hidden because `uv run` silently falls back to an ambient
    interpreter when it cannot find a project. Switching the launcher to an
    explicit `uv sync` is what finally surfaced it, as a plain "No pyproject.toml
    found in current directory or any parent directory".
    The previous commit message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
2026-08-07 Warn before a delid or relid that cannot physically happen
    Triggering "Delid Plate" from the Processes tab against a plate with no lid
    produced no warning the operator would notice. The backend refused correctly —
    bravo.delid_plate raises "does not currently have a lid", and DelidPlateTask
    raises again — but the refusal reached the UI as a generic "API error: ..."
    line in the log panel, after dispatch, easy to miss.
    The cause is in the UI. deck_details has always carried is_lidded, but
    describeDeckLocationLabware returns only detail.name, so a lidded plate and a
    bare one rendered as the same string. The panel had the answer and discarded
    it, and the location dropdowns offer every deck p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
2026-08-07 Open the Designer in a new tab
    The Designer was the only header link that navigated in place. Labware Editor,
    Liquid Class Editor, Tip Editor and Vision Calibration all already open in
    their own tab — ensureEditorLinks() gives each target="_blank" with
    rel="noopener noreferrer" — so this just makes the one hand-written link in
    index.html match its siblings.
    Beyond consistency: navigating away tears down the control panel's WebSocket,
    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
2026-08-08 Correct noise range for W position register
    Updated the noise range for the W position register from 5–10 µL to 0.05-0.1 µL between reads.
2026-08-09 Add an optional jelly button skin, toggled with Cmd+Option+Shift+V
    Jelly UI itself turned out to be the wrong tool. It is a Web Components
    library, not a CSS theme: 40 custom elements in a 311 KB module, each rendering
    a real <button> inside a shadow root. Adopting it would mean replacing button
    markup, and shadow DOM would cut this project's button CSS off from the button
    interior — including the rules that make gated motion controls look inert.
    Rebuilding those through ::part() is a poor trade for a visual preference, so
    this is a hand-written skin instead: no dependency, no DOM changes, and the
    safety gating keeps working untouched.
    The skin is additive and scoped to :root[data-jelly="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
2026-08-09 Fix Tips On/Off in a loop: returns after the first one were illegal
    A Loop containing Tips On then Tips Off moved exactly one block of tips and
    then failed. Three defects, all in the same path.
    1. head_mode._is_legal_tipbox_anchor applied the same packing rule to returns
    as to pickups: nothing may be occupied outboard of the candidate block,
    measured from the mirror corner. That is right for a pickup — it forces the
    head to take the outermost remaining block instead of orphaning tips — but
    backwards for a return. Once the first Tips Off filled the corner columns,
    every remaining anchor had occupied cells outboard of it, so a destination
    box went from 23 legal return an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
2026-08-09 Show returned tips, stop picked tips reappearing, honour the return anchor
    Follow-up to 8b04579. Three more defects in the same area, two of them purely
    in what the viewer is told.
    The 3D view models a tip box as "these cells are missing", and both directions
    of that were wrong:
    - _set_removed_tip_cells assigned rather than accumulated, so each Tips On
    replaced the record of the previous pickup. Every tip taken in an earlier
    loop iteration popped back into view, which is why the source box appeared
    to refill itself between iterations.
    - A box that started empty had no removed-cell baseline, so _restore_tip_cells
    had nothing to subtract from and bailed out early. Tips ejected into a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
    [simulation.yaml]
2026-08-09 Bump the JS cache-buster tokens so frontend fixes actually load
    The tip-box rendering fix in 4b05b39 was correct and being served, but no
    browser was running it. designer.html imports the module as
    robot-scene.js?v=stickytargets1
    and index.html as main.js?v=init3. Browsers cache ES modules by full URL, so
    leaving those tokens untouched pins every client to the version it first
    fetched however new the file on disk is. The symptom matched the pre-fix code
    exactly — source box rendering correctly, destination box drawing no tips —
    because that is precisely what was still executing.
    Both modules changed today, so both tokens move. Comments now say why they
    exist, since the mechanism i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
2026-08-09 Report tip-box fill state in deck_details
    Found while trying to reproduce a reported head-alignment issue: a box
    configured empty rendered with all 384 tips. deck_details carried no fill
    state, so the 3D view — which falls back to that when it has no per-cell
    occupancy — had no way to know, and drew every tip box as full until a
    workflow started reporting.
    The value is derived from live inventory rather than the original
    configuration, so it stays true as tips move: full, empty, or partial. It is
    attached only to the top of a stack, since a riser under a tip box is not
    itself one. Untracked boxes keep reporting full, matching how they already
    behave everywhere else.
    Verified against a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
2026-08-09 Align the rendered head barrels with the tip box wells
    The 3D view drew the head's barrels a constant 10.4 mm (2.3 columns) left and
    4.5 mm (1 row) off from the wells they were over. Invisible mid-array in a full
    box; obvious at the edge of an empty one, which is why it read as a Tips Off
    problem. Measurement showed the same error at Tips On and Tips Off alike, so it
    was never specific to either.
    _getHeadTipMountFrame infers the array from the bounding box of the head mesh's
    bottom slice, so it picks up shroud and mounting structure. The array centre is
    now derived from the deck instead, using the physical invariant that the head's
    A1 barrel sits exactly over the box's A1 well:
    - deck sl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
2026-08-09 Give the designer the teachpoints its head alignment depends on
    933b973 derived the head's barrel positions from the deck mapping, and measured
    correctly in isolation — but it never ran in the designer, which is the one
    place the misalignment was reported.
    The mapping is built from teachpoints, and the scene only ever receives those
    from the live /ws/state feed (_handleStateUpdate). `setTeachpoints` is called by
    nobody, and the designer pauses that socket for the duration of a simulation via
    setSimulationMode. So in the designer `this.teachpoints` stays empty, the deck
    motion map is null, and the head tips silently fall back to being inferred from
    the head mesh's bounding box — the orig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
2026-08-09 Document where A1 is in the 3D head model
    The 3D view draws the head's barrels a couple of columns from the wells they
    are over, worst at the edge of an empty tip box. The cause is that the renderer
    does not know where A1 is: _getHeadTipMountFrame guesses it from the bounding
    box of the head mesh's bottom slice, which includes shroud and mounting
    structure.
    This is the definition it should use instead. Scoped hard to the 3D view: real
    motion is correct in full, row, column and partial modes on both 96 and 384
    heads, so the geometry under pybravo/ is authoritative and untouched. The
    document says so at the top, and lists an empty `git diff -- pybravo/` as a
    completion criterion.
    Records wha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
2026-08-09 Mark the URDF alignment work as unfinished
    The misalignment is still present: A1_OFFSET is unmeasured and the renderer is
    unchanged. Two attempts were made and both reverted, so the 3D view is no worse
    than before, just not yet better. Cosmetic only — real motion is unaffected.
2026-08-09 Record the Z-axis half of the URDF alignment problem
    The head renders 44.1 mm too low at any commanded Z. Measured with a 384 tip
    box on the deck: at Tips On (Z=115.1, seated on the box) the head mesh bottom
    draws at 36.0 mm against a box top of 80.1 mm, and the same 44.1 mm error
    appears at the Tips Off pose.
    The arithmetic is not at fault. Moving between the two poses raised the head by
    exactly 14.2 mm, which is tips_off_z_offset from config/tip_offsets.yaml — the
    backend already folds the offsets into the commanded Z and the view reproduces
    that faithfully. The offsets must therefore not be applied again in the
    renderer; that would double-count them.
    The error is a constant, so it is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
2026-08-09 Draw the head at the right height: Z is referenced to the teach tip
    The head rendered one teach tip too low at every Z. Robot Z is referenced to
    the tip of the teach tip, not the barrel face — the backend computes
    deck_surface_z as teach_z + teach_tip_length — but the renderer placed the head
    as though Z meant the barrel.
    JOINT_AXIS_MAP already carries a homeOffset per joint, calibrated at 193.04 for
    X and -20 for Zg but left at 0 for Z. It now adds the head's teach tip length,
    taken live from head.teach_tip_length_mm on /api/profile so a different head or
    teach tip follows automatically, with 26.1 seeded as a fallback.
    Confirmation sweep, head mesh only against the deck surface, at Z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
2026-08-09 Move the tip exchange to the press, and fix the X/Y visual datum
    Two remaining 3D-view defects from the tips-in-a-loop work, both display-only.
    Timing. On Tips On the tips vanished from the box before the head had begun to
    descend, then appeared on the head only after it had retracted. Two causes in
    the simulate animation (_animate_task_motion, preview-only — the sole call
    site is gated on preview_animation, which execute mode disables):
    - _tip_change_event serializes _tipbox_removed_cells at build time, and the
    inventory mutation ran before BOTH events were built — so the pre-press
    event already carried the emptied box. The mutation now sits between the two
    builds: the approach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
2026-11-11 Home G on a Darwin cold start when the pre-home open is refused
    On a Darwin Bravo, initialize opens the gripper before homing G. The
    controller refuses any move on an axis that has not been homed since
    power-up, so on a cold start both pre-home open moves were refused and
    the step failed with "Could not open gripper wide enough to finish
    initialization" before homing was ever attempted.
    When the open move is refused specifically because G is not homed, and
    the plate sensor positively reads clear, initialize now continues to G
    homing. A pre-open move that fails for any other reason, or a plate
    sensor that cannot be read, still stops initialization as before.
    The Darwin controller now report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
2026-11-11 Update three tests left stale by earlier behaviour changes
    Each test was broken by a commit that changed behaviour on purpose and
    updated its other tests but missed this one. No product code changes.
    - Designer draft routing: runWorkflow now resets the physical
    obstruction preview, so the Node harness needs the same three stubs
    the sibling Designer tests already define.
    - Repeated transfer simulation: the partial tip rack offered columns
    11-12 at deck position 3, which a back-left single column cannot
    reach inside the configured X range (473 mm needed, 390 mm allowed)
    and which the tip reachability check now rejects. The rack offers
    columns 1-2 instead. The strict-failure test t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
2026-11-11 Restore the simulation profile and tip definitions
    The previous commit picked up two config files as the running app had
    re-saved them, which dropped their comments and changed values that
    tests and the simulator rely on:
    - profiles/simulation.yaml had use_ethernet and vision.enabled switched
    to true.
    - config/tips.yaml lost the 15, 50 and 51 uL tip definitions, so the
    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
2026-11-12 Assign Processes-panel labware without a confirmation dialog
    Choosing a value in the Processes panel's Labware dropdown asked for
    confirmation before assigning it to the deck location. Operators change
    this often, including with the scroll wheel, and the prompt got in the
    way. The dropdown now assigns immediately; the "Assigned ... to location
    N" log line remains as the record of what changed.
    Frontend only. The assignment still goes through the same deck labware
    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
2026-11-12 Accept reviewed dead volumes in the checked-in catalog tests
    Two tests pinned the labware catalog as it stood before it was edited in
    the labware editor, and have failed since those edits were committed.
    The catalog is unchanged here; the tests and the doc now describe it.
    - Dead-volume status: six plates in the snapshot and editor YAML were
    marked reviewed in the labware editor, which is a deliberate action
    (editing a value returns it to placeholder). Those two editor-written
    stores may now carry placeholder or reviewed. The overlay and the
    Mongo seed, which the editor never writes, must still ship
    placeholders only. The numeric, positive and below-capacity checks
    are unchanged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
2026-11-12 Add agent planning to the Protocol Assistant
    The Protocol Assistant gains a conversational sidebar and an interface
    for external planners. Neither can dispatch hardware or approve a
    protocol; both stay in the existing application flow.
    - Staged suggestions: a chat edit is stored as a pending proposal
    against the session revision it was made from, shown with its changed
    fields and ordered task cards, and applied only when accepted. A
    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
2026-11-12 Record new profile defaults in 384.yaml; ignore the active-profile marker
    profiles/384.yaml is as the server re-saved it after a connect. The only
    change is that fields added to the profile schema since it was last
    saved are now written out with their default values: the cartridge
    shuck G and Zg distances (4.0 and 20.0 mm) and a 0.0
    darwin_calibration_offset on each axis. No axis range, limit or
    teachpoint changes.
    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
